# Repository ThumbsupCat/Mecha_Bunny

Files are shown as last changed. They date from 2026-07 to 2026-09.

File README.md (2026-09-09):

# Mecha-Iepurele (Mechanized Bunny)

**Author:** Alice Dobre
**Date:** 2026-07-20  

> Documentation draft generated from Agent 0 and Agent 1 outputs.  
> AI assists. Humans decide.

## 1. Introduction

Mecha-Iepurele (Mechanized Bunny) is an interactive, moving robotic companion designed for indoor flat surfaces (classroom, table, or smooth floor). The robot engages in natural conversations with humans via a cloud-based Conversational AI API and physically tracks and follows the user. High-level network operations (Wi-Fi connectivity, HTTPS API transactions, JSON payload parsing, and direct Text-to-Speech audio rendering via an I2S DAC) are offloaded to an ESP32 coprocessor suite (ESP32-S3 Nano), while low-level motor control loops, servo ear, active steering, battery monitoring, and sensor processing are managed by the main microcontroller board.

The purpose of this project is to create an engaging physical robotic companion that bridges low-level embedded hardware (sensors, motor drivers, PWM actuators, power management) with cloud-based artificial intelligence. The project originated from a concept for a mechanized bunny that talks to users, mimics emotional expressions based on conversation mood, and follows the user.

This project is especially valuable for third-year Computer Science students participating in the Embedded Engineering and Gen AI Summer School, as it teaches core embedded concepts (UART communication, PWM signal generation, I2C/I2S interfacing, control loops, power isolation, and software debouncing) as well as networking, API parsing, privacy protection, and system integration.

The **NXP FRDM-MCXA153 board featuring the NXP MCXA153 MCU** is selected as the mandatory target controller for all summer school projects. It provides Arm Cortex-M33 real-time processing, low-power timer peripherals, LPUART interfaces, and ADC channels required for local actuator control and sensor processing.

> This documentation is a draft and must be validated by students and instructors before implementation.

---

## 2. General Description

### 2.1 Project Summary

- **Project Name:** Mecha-Iepurele (Mechanized Bunny)
- **Author / Student Team:** TODO: Add Student Author(s) Name(s) and Student ID(s)
- **Short Summary:** An interactive, moving mechanized bunny robot that communicates with a human via an AI API (over ESP32 Wi-Fi) and mimics emotional expressions using physical movement (ear sweeps states).
- **Main Objective:** Build a robotic companion that uses a FRDM-MCXA153 board for local sensor-motor control and expressions, and an ESP32-S3 Nano for Wi-Fi connection to a cloud conversational AI API that provides responses and mood data.
- **Intended Users:** Third-year university Computer Science students and summer school reviewers/instructors.
- **Operating Environment:** Indoor flat surfaces (classroom, laboratory table, or smooth floor) with active Wi-Fi connectivity.
- **Selected Scope:** Recommended Summer School Version featuring mobile hopping locomotion via a single central DC motor driving a double-crank axle, active steering via a rear tail-skid servo, ear expression servos, ultrasonic user tracking, direct I2S TTS voice output on the ESP32, and onboard USB-C 2S LiPo balance charging.
- **Main Behavior:** Upon boot, the bunny initializes peripherals and connects to Wi-Fi. When user conversation is triggered, the ESP32 queries the cloud AI API, receives text response and mood data, and streams TTS voice output through an I2S DAC/speaker. The ESP32 sends servo targets to the MCXA153 via UART (with ACK confirmation). The MCXA153 updates ear servos (drooping for sad, perking for happy) state. Concurrently, a 50 ms motor control loop reads an ultrasonic sensor to track user distance (maintaining 30–50 cm) and drives the central hopping DC motor and steering tail-skid servo to follow the user smoothly.
- **Inputs:**
  - Ultrasonic distance sensor (RCWL-1601 / HC-SR04P, 3.3V compatible) measuring user distance.
  - Tactile physical buttons (setup / Wi-Fi provisioning / emergency stop).
  - Wi-Fi connection to Cloud LLM/NLP API (via ESP32-S3 Nano coprocessor).
  - Battery voltage diagnostic signal via resistor divider to ADC.
- **Outputs:**
  - 1x Central high-torque DC TT gear motor (via TB6612FNG H-bridge driver) for 90-degree kick hopping locomotion.
  - 4x SG90 Micro Servos (2x ears, 1x rear steering tail-skid).
  - MAX98357A I2S Audio DAC + 8 Ohm 2W speaker (driven directly by ESP32-S3 Nano).
- **Out-of-Scope Items:**
  - On-board execution of heavy Large Language Models (LLMs) or local Speech-to-Text on the MCXA153.
  - High-speed navigation on rough terrain or stairs.
  - Complex multi-obstacle collision avoidance beyond tracking the primary user.
  - Custom cloud backend hosting (standard pre-existing HTTP REST AI endpoints are assumed).
  - Status LEDs (all status feedback is expressed organically through physical ear movements).
  - OLED screen displays and local web input pages (in the speech TTS direct-drive edition).

### 2.2 Feature Tiers

| Tier | Description | Main Features | Extra Components | Main Risks | Suitability |
|---|---|---|---|---|---|
| **Core** | Static Ear desktop prototype in shell | ESP32-S3 Nano Wi-Fi handshake, queries mock/REST API, direct TTS audio via I2S MAX98357A DAC, MCXA153 drives 2x ear servos, NVS data wiping, UART ACK comms | ESP32-S3 Nano, MAX98357A DAC + Speaker, 2x Ear Servos, 3D Printed Shell & Brackets | UART framing errors, Wi-Fi handshake timeout, API parsing failure | **High suitability:** Focuses on serial comms, basic GPIO, and PWM servo control. Realistic for early development. |
| **Recommended** | Mobile Speech Companion (Selected Target Scope) | All Core features plus differential hopping leg linkage (1x central DC TT motor + H-bridge) executing gentle 90-degree kicks, active steering rear tail-skid, ultrasonic distance tracking (30–50 cm window), 50 ms motor loop, battery ADC monitoring (<6.4V sleep), 2S LiPo balance charging via USB-C port, magnetic quick-release ventilated shell | 1x DC TT Motor, TB6612FNG Driver, 3.3V Ultrasonic Sensor, 2S LiPo Battery & BMS, 2S USB-C Balance Charger Module, 4x Servos (Ears, Steering), USB-C Panel Cable, MR85ZZ Bearings, PETG/TPU Filaments | Mechanical binding, leg joint wear, high component density heat, ground impact shock, battery over-discharge | **Good with guidance:** Combines PWM, control loops, mechanical kinematics, power isolation, and safety. Excellent depth. |
| **Advanced** | Voice-Input Speech Companion | All Recommended features plus local I2S MEMS microphone (INMP441) on ESP32-S3 Nano for voice command streaming, wake-word detection / TinyML keyword spotting, local fuel gauge | INMP441 I2S MEMS Mic, LiPo Fuel Gauge IC, Camera module (ESP32-CAM / HuskyLens) | Acoustic feedback loops, double-buffered I2S timing, high power draw, memory limits | **Low (Optional extension):** Suitable only as a capstone extension for advanced teams due to time limits. |

### 2.3 Scenarios

| ID | Scenario | Description |
|---|---|---|
| `SC-001` | Startup / Setup | Device powers on. MCXA153 initializes GPIOs, LPUART, ADC, and PWM timers. ESP32-S3 Nano reads Wi-Fi credentials from NVS and connects to Wi-Fi. Upon successful connection, ESP32 sends "Online" byte over UART. MCXA153 sweeps ears to neutral to confirm awake state. |
| `SC-002` | Dynamic Wi-Fi Provisioning | If Wi-Fi fails within 15 seconds or setup button is held for 5 seconds at boot, ESP32 launches an Access Point setup portal. Ears move slowly to indicate search state. User connects via smartphone, submits credentials, and ESP32 connects and the ears showing attention state. |
| `SC-003` | Multi-User Device Wiping | Tester A finishes testing. Tester A holds setup button for 10 seconds. ESP32 erases all stored Wi-Fi credentials, tokens, and caches from NVS, reboots, sweeps ears to neutral to sleep. |
| `SC-004` | Onboard Battery Charging | When battery drops below 6.4V, MCXA153 halts motors. User plugs standard 5V USB-C cable into shell port. Integrated 2S balance charger charges cells to 8.4V. |
| `SC-005` | Normal Operation & Speech Playback | Conversation is triggered. ESP32 queries Cloud AI REST API, receives JSON (response text, mood tag, servo angles), extracts servo targets, and requests TTS audio stream. ESP32 renders audio via I2S to MAX98357A DAC. |
| `SC-006` | Active Privacy Cleansing | Speech playback completes. ESP32 immediately fills audio buffers and text RAM strings with zeros (`0x00`). Subsequent API calls use a newly generated, isolated session UUID to prevent user profiling. |
| `SC-007` | Actuator Expression Control | ESP32 sends parsed servo angles and mood data over LPUART to MCXA153. MCXA153 updates FTM/TPM PWM registers, driving ear servos to sweep to target angles (drooping for sad, perking for happy). |
| `SC-008` | Distance Sensor Processing | MCXA153 runs a periodic 50 ms motor loop. It triggers the ultrasonic sensor with a 10 us pulse, measures Echo pin return duration, and calculates distance in centimeters. |
| `SC-009` | Proximity Hopping & Steering | User is detected at 80 cm, offset right. MCXA153 drives central DC motor via PWM. Shared double-crank axle sweeps leg linkages past 90 degrees vertical, executing a gentle downward shove that hops chassis forward. Simultaneously, steering servo pivots rear tail-skid right for a smooth turn, slowing down as distance reaches 30–50 cm window. |
| `SC-010` | Safety & Reliability (Sleep Halt) | Emergency stop button is pressed, sensor Echo hangs >250 ms, or battery falls <6.4V. MCXA153 forces motor PWM to 0%, pulls motor driver STBY low, centers steering servo, droops ears to asleep state. |

### 2.4 User Stories

| ID | User Story |
|---|---|
| `US-001` | As a student developer, I need to use the NXP FRDM-MCXA153 board, so that the project complies with the course's mandatory hardware platform. |
| `US-002` | As a user, I need the bunny to dynamically connect to different Wi-Fi networks using a setup mode, so that I can easily bring the companion to new environments. |
| `US-003` | As a tester, I need to easily wipe my Wi-Fi credentials and conversation logs from the device, so that my personal network keys and private voice contents are not exposed to subsequent testers. |
| `US-004` | As a tester, I need the communication to be encrypted and my conversation session ID to be isolated, so that my conversations cannot be intercepted on local Wi-Fi or linked to other testers' profiles. |
| `US-005` | As a user, I need the bunny to convey its state of sleep and activity through physical movements of the ears, so that it looks like an organic creature without unnatural flashing LEDs. |
| `US-006` | As a developer, I need to power the motors and microcontrollers from a single large LiPo battery with separate regulators, so that logic circuitry is fully isolated from motor transients. |
| `US-007` | As a user, I want the bunny to move by hopping like a real rabbit, utilizing a robust leg linkage system that avoids binding, joint wear, and synchronization failures. |
| `US-008` | As a builder, I need structural mounts and leg linkages printed with PETG filament and low-friction bearings, so that the hopping mechanism has high toughness and structural durability. |
| `US-009` | As a builder, I need a spacious ventilated body shell with magnetic latches, an onboard USB-C 2S balance charger, and a 2S BMS protection board, so that components fit safely and battery charging is convenient and safe. |
| `US-010` | As a student builder with a 7-week project timeline, I need pre-designed mechanical model templates (STL/STEP) to build from, or I must strictly limit custom Blender CAD learning and design to a maximum of 1 week. |
| `US-011` | As a user, I need the bunny to be able to take motion turns when necessary, so that it can steer around obstacles or track my position as I turn corners. |
| `US-013` | As a builder, I want a non-piston leg linkage that hops the whole body by rotating the leg to 90 degrees relative to the body, executing a gentle low-amplitude hop to keep the movement stable and protect components. |

### 2.5 Use Case Diagram

```mermaid
flowchart LR
    Student[Student Developer]
    User[User / Tester]
    Instructor[Instructor / Reviewer]

    UC1((Initialize System & Hardware))
    UC2((Provision Wi-Fi Credentials))
    UC3((Trigger Conversation Session))
    UC4((Query Cloud AI & Stream TTS))
    UC5((Animate Ear Expressions))
    UC6((Track User & Proportional Hop))
    UC7((Pivot Rear Steering Tail-Skid))
    UC8((Trigger Organic Sleep / Halt))
    UC9((Wipe Credentials & Clean RAM))
    UC10((Charge 2S LiPo via USB-C))
    UC11((Review Test Evidence & Code))

    Student --> UC1
    User --> UC2
    User --> UC3
    UC3 --> UC4
    UC4 --> UC5
    UC3 --> UC6
    UC6 --> UC7
    User --> UC8
    User --> UC9
    User --> UC10
    Instructor --> UC11
```

### 2.6 Hardware and Software Block Diagram

```mermaid
flowchart TD
    subgraph PowerSystem["Power Subsystem"]
        BAT["2S LiPo Battery (7.4V - 8.4V)"]
        BMS["2S BMS Protection Board (6.0V Cutoff)"]
        CHG["2S Balance Charger Module (IP2326/TP5100)"]
        USBC["Panel USB-C Port"]
        REG_LOGIC["3.3V / 5.0V Logic Regulator"]
        REG_MOTOR["5.0V / 6.0V Motor & Servo Regulator"]
        BATT_DIV["Resistor Voltage Divider (10k / 4.7k)"]

        USBC --> CHG
        CHG --> BMS
        BAT <--> BMS
        BMS --> REG_LOGIC
        BMS --> REG_MOTOR
        BMS --> BATT_DIV
    end

    subgraph ESP32Core["ESP32-S3 Nano Coprocessor"]
        WIFI["Wi-Fi 2.4GHz Engine"]
        REST["HTTPS Client & JSON Parser"]
        I2S_OUT["I2S Digital Audio Output"]
        NVS["NVS Storage (Credentials & Keys)"]
    end

    subgraph MCUCore["NXP FRDM-MCXA153 Main Controller"]
        LPUART["LPUART Interface (115200 8-N-1)"]
        PWM_TIMERS["FTM / TPM Timer PWM Generators"]
        GPIO_CTRL["GPIO Controllers"]
        ADC_CTRL["12-bit ADC Input"]
        SUPERLOOP["Superloop & State Machine Task"]
    end

    subgraph AudioOutput["Audio Output Subsystem"]
        DAC["MAX98357A I2S DAC Amplifier"]
        SPK["8 Ohm 2W Speaker"]
        DAC --> SPK
    end

    subgraph ActuatorsSensors["Sensors & Actuators"]
        US_SENS["Ultrasonic Distance Sensor (RCWL-1601)"]
        EAR_L["Left Ear Servo (SG90)"]
        EAR_R["Right Ear Servo (SG90)"]
        STEER["Rear Steering Servo (SG90)"]
        TB6612["TB6612FNG H-Bridge Motor Driver"]
        DCMOTOR["Central DC TT Gear Motor"]
        ESTOP["Emergency Stop / Setup Button"]
        LINKAGE["Double-Crank Hopping Leg Linkage (PETG)"]

        TB6612 --> DCMOTOR
        DCMOTOR --> LINKAGE
    end

    %% Power distribution flow
    REG_LOGIC -.->|3.3V Power| ESP32Core
    REG_LOGIC -.->|3.3V Power| MCUCore
    REG_LOGIC -.->|3.3V Power| US_SENS
    REG_MOTOR -.->|5V/6V Power| DAC
    REG_MOTOR -.->|5V/6V Power| EAR_L
    REG_MOTOR -.->|5V/6V Power| EAR_R
    REG_MOTOR -.->|5V/6V Power| STEER
    REG_MOTOR -.->|5V/6V Power| TB6612

    %% Inter-processor data flow
    ESP32Core <== LPUART ACK Protocol ==> MCUCore
    I2S_OUT ==> DAC

    %% MCU Control connections
    BATT_DIV --> ADC_CTRL
    US_SENS <== GPIO / Capture ==> MCUCore
    ESTOP --> GPIO_CTRL
    PWM_TIMERS --> EAR_L
    PWM_TIMERS --> EAR_R
    PWM_TIMERS --> STEER
    PWM_TIMERS --> TB6612
    GPIO_CTRL --> TB6612
```

**System Architecture Explanations:**

- **Power Flow:** Power originates from a 2S LiPo battery pack (7.4V nominal, 8.4V max) connected through a 2S BMS protection board (6.0V cutoff). Power is split into two independent buck/LDO regulators: a digital logic regulator supplying 3.3V to the MCXA153, ESP32-S3 Nano, and ultrasonic sensor; and a motor/actuator regulator supplying 5.0V/6.0V to the TB6612FNG driver, MAX98357A DAC, and 4x SG90 servos. An onboard 2S USB-C balance charger (IP2326 or TP5100) charges the pack via a shell-mounted USB-C port.
- **Data & Control Flow:** The ESP32-S3 Nano executes Wi-Fi handshakes and cloud HTTPS transactions. Audio data streams directly over I2S to the MAX98357A DAC and speaker. Parsed servo targets, mood data, and system commands are sent to the MCXA153 over LPUART at 115200 baud. The MCXA153 validates checksums, returns software ACK bytes, updates servo PWM registers, and executes the 50 ms ultrasonic distance tracking loop to modulate the central DC motor and steering servo.
- **Compatibility Concerns:** MCXA153 GPIO pins operate strictly at 3.3V (max 4 mA per pin). Motor and servo power rails must never connect to MCU logic pins. A 3.3V-compatible ultrasonic sensor (RCWL-1601) is used, or a 10k/4.7k resistor divider is inserted on the Echo pin if using 5V HC-SR04 models. Battery voltage (up to 8.4V) is scaled down via a 10k/4.7k divider so the ADC receives <= 2.68V.
- **Protection & Decoupling:** Decoupling capacitors (100 uF electrolytic + 0.1 uF ceramic) are placed across power rails near the motor driver and servos to suppress inductive current spikes and prevent MCU brownouts. A freewheeling diode protection network is integrated inside the TB6612FNG driver.
- **Datasheet Checks Required:**
  - NXP MCXA153 reference manual: verify LPUART0 pin muxing, FTM/TPM timer channel assignments, and 12-bit ADC input channels.
  - TB6612FNG datasheet: check VM logic input ranges, logic VCC (3.3V), and STBY pin pull-down behavior.
  - MAX98357A datasheet: verify bit clock (BCLK), word select (LRCK), and serial data (SDIN) timing parameters for ESP32 I2S.
  - 2S BMS & Charger datasheets: confirm overcharge threshold (4.25V) and over-discharge threshold (3.0V per cell).

---

## 3. Hardware Design

### 3.1 Bill of Materials

| # | Component | Qty | Tier | Purpose | Likely Interface | Voltage / Power Notes | Risks / Checks |
|---|---:|---:|---|---|---|---|---|
| 1 | NXP FRDM-MCXA153 | 1 | Core | Central low-level MCU board for motor loop, PWM servos, ADC, and distance timing | LPUART, PWM, GPIO, ADC | 3.3 V Logic; Powered via USB-C or regulated 3.3V pin | Mandatory board. Verify pinout and 3.3V logic boundaries. |
| 2 | ESP32-S3 Nano | 1 | Core | Wi-Fi coprocessor, HTTPS API client, JSON parser, I2S audio renderer, NVS storage | LPUART, I2S, Wi-Fi | 3.3 V Logic; Powered via regulated 3.3V rail | Confirm NVS data wiping and 115200 baud UART link. |
| 3 | MAX98357A I2S DAC | 1 | Core | Direct digital audio decoding and amplification for voice TTS output | I2S (BCLK, LRCK, DIN) | Powered via 5V rail; 3.3V I2S logic from ESP32 | Audio noise from power ripples; route I2S away from UART. |
| 4 | Dynamic Speaker (8 Ohm, 2W) | 1 | Core | Voice TTS output speaker | Direct wire to DAC | Driven by MAX98357A DAC output | Ensure secure mounting inside head/body shell. |
| 5 | SG90 Micro Servos | 4 | Core / Rec | Physical actuators: 2x Ears, 1x Rear Steering Tail-skid | FTM/TPM PWM (50 Hz) | 5V Power rail; 3.3V PWM control logic | Current spikes during stall can reset MCU; use dedicated 5V regulator. |
| 6 | High-Torque DC TT Gear Motor | 1 | Recommended | Drives shared double-crank axle for 90-degree kick hopping locomotion | PWM + 2x GPIO (TB6612) | Powered via 5V-6V motor regulator rail | Inductive noise spikes; require freewheeling diodes & decoupling. |
| 7 | TB6612FNG H-Bridge Motor Driver | 1 | Recommended | Controls speed and direction of central DC gear motor | PWM, 2x GPIO, STBY pin | VM 5V-6V, VCC 3.3V logic | Verify STBY pin default low for safe shutdown. |
| 8 | Ultrasonic Distance Sensor (RCWL-1601) | 1 | Recommended | Measures distance to user (30-50 cm window) for proportional following | GPIO Trigger / Echo Capture | 3.3V Power & Logic | Sensor timeout hang; software 250ms watchdog required. |
| 9 | 2S LiPo Battery Pack (7.4V, 1500+ mAh) | 1 | Recommended | Main power source for mobile robot | 2S JST-XH balance + XT30/T-plug | 7.4V nominal (8.4V max, 6.0V cutoff) | Fire / thermal hazard; requires BMS board & balance charger. |
| 10 | Dual Buck / LDO Regulators | 2 | Recommended | Independent voltage regulation: 1x 3.3V logic, 1x 5V/6V motor & servos | Power rails | Input 7.4V; Output 3.3V and 5.0V | Heat dissipation; check continuous current ratings (>= 2A for motor rail). |
| 11 | 2S USB-C Balance Charger Module (IP2326/TP5100) | 1 | Recommended | Onboard USB-C balance charging for 2S battery pack | USB-C input, 2S balance output | Input 5V USB-C; Output 8.4V balance charge | Verify auto cut-off at 8.4V. |
| 12 | 2S LiPo BMS Protection Board | 1 | Recommended | Battery safety cutoff (overcharge, over-discharge, overcurrent) | Series battery connection | Cutoff at 6.0V overall pack voltage | Verify overcurrent protection >= 4A. |
| 13 | USB-C Panel Mount Extension Cable | 1 | Recommended | Exposes charging port to outer body shell | USB-C | 5V 2A pass-through | Ensure solid mounting on shell exterior. |
| 14 | MR85ZZ Ball Bearings | 8-12 | Recommended | Low-friction pivot bearings for double-crank leg linkages | Mechanical press-fit | N/A | Prevents mechanical binding and motor stalls. |
| 15 | Neodymium Magnets (4x2 mm) | 8-12 | Recommended | Toolless quick-release magnetic latches for outer body shell | Mechanical recess | N/A | Allows instant access to debugger and internal electronics. |
| 16 | M3 Socket Fastener Kit | 1 pack | Core / Rec | Structural assembly screws, nylon locknuts, and washers | Mechanical | N/A | Ensure nylon locknuts prevent loosening during hopping. |
| 17 | Tactile Push Buttons | 2 | Core / Rec | Setup / Wi-Fi provisioning button & Emergency Stop button | GPIO with internal pull-up | 3.3V Logic | Software debouncing required (20 ms window). |
| 18 | PETG 3D Filament | ~300g | Recommended | Structural mounts, crank arms, steering brackets, leg links | 3D Printed | N/A | High impact toughness required for hopping landing stress. |
| 19 | TPU 3D Filament | ~100g | Recommended | Flexible feet landing pads and shock absorbers | 3D Printed | N/A | Shore hardness ~95A for ground traction and shock damping. |
| 20 | PLA 3D Filament | ~300g | Recommended | Spacious outer body shell (~180x120x120 mm) with ventilation grilles | 3D Printed | N/A | Non-stress enclosure. Sourced STL files recommended. |

### 3.2 Hardware Block Diagram Description

The Mecha-Iepurele hardware architecture is organized around a dual-processor design to isolate real-time motor and sensor control from network latency:

- **Main Controller (NXP FRDM-MCXA153):** Serves as the central low-level executive. It runs a deterministic 50 ms superloop that handles PWM generation for 4x SG90 servos (left ear, right ear, , rear steering tail-skid), PWM speed and direction control for the central DC motor via the TB6612FNG H-bridge, GPIO pulse timing for the ultrasonic distance sensor, ADC voltage sampling for battery diagnostic monitoring, and UART packet parsing with ACK generation.
- **Coprocessor (ESP32-S3 Nano):** Manages all high-level Wi-Fi communications, TLS encryption, REST API transactions with the cloud AI endpoint, JSON response extraction, NVS credential storage/wiping, and direct I2S digital audio decoding to the MAX98357A DAC.
- **Power Architecture:** Powered by a single 2S LiPo battery pack (7.4V nominal, 8.4V max). Safety boundaries are enforced by a 2S BMS protection board that disconnects power if overall pack voltage drops to 6.0V (3.0V per cell) or current exceeds 4A. Two independent voltage regulators are fed from the BMS output: a 3.3V logic regulator powers the MCXA153, ESP32-S3 Nano, and ultrasonic sensor; a separate 5.0V/6.0V high-current regulator powers the TB6612FNG motor driver, 4x SG90 servos, and MAX98357A audio DAC. Battery voltage is monitored via a 10k / 4.7k resistor voltage divider connected to an ADC pin on the MCXA153 (delivering <= 2.68V at fully charged 8.4V). Onboard balance charging is achieved via an IP2326 or TP5100 2S balance charger module connected to a panel-mounted USB-C port on the outer shell.
- **Sensors & Actuators:**
  - *Ultrasonic Distance Sensor:* RCWL-1601 (3.3V native) mounted on the front chest/head to measure user distance.
  - *Hopping Locomotion:* 1x central DC TT gear motor drives a shared double-crank axle. Left and right leg linkages are physically locked in phase to the axle, preventing tipping. The leg linkages act as rotary levers; when sweeping through the 90-degree vertical angle relative to the chassis, they execute a gentle downward shove against the ground, lifting the body 5–15 mm into a forward hop/scoot. MR85ZZ ball bearings at all pivot joints minimize friction, while TPU pads on the feet absorb landing shock.
  - *Active Steering:* An SG90 micro servo pivots a rear tail-skid or caster assembly left/right by +/-30 degrees to steer the robot dynamically during hopping.
  - *Organic Expression Actuators:* 2x SG90 servos sweep the ears (drooped = sad, perked = happy/listening, neutral = idle);
- **Protection & Compatibility:** Logic connections between 3.3V MCU pins and 5V components use resistor dividers or 3.3V native modules. Decoupling capacitors (100 uF electrolytic + 0.1 uF ceramic) buffer voltage dips near the motor driver and servos. Datasheet reviews must verify pin mux assignments in MCUXpresso Config Tool, LPUART baud rate clocks, and ADC reference voltage calibration.

### 3.3 Pin Allocation Draft

Generic FRDM-MCXA153 capability only - exact pin requires board pinout and datasheet verification.

| Component | Tier | Signal | Required MCU Capability | Suggested Pin / Capability | Voltage Level | Direction | Interface | Verification Needed |
|---|---|---|---|---|---|---|---|---|
| ESP32-S3 Nano | Core | UART_TX | LPUART RX input | Generic LPUART0_RX | 3.3 V | Input | UART (115200) | Confirm configuration matches LPUART peripheral routing in MCUXpresso Pin Mux tool. |
| ESP32-S3 Nano | Core | UART_RX | LPUART TX output | Generic LPUART0_TX | 3.3 V | Output | UART (115200) | Verify TX buffer is set to push-pull drive and baud rate clock is accurate. |
| Battery Sense | Rec | BATT_VSENSE | ADC Analog Input | Generic ADC Channel | <= 2.68 V | Input | Analog ADC | Verify 10k/4.7k resistor divider output does not exceed 3.3V at 8.4V max battery charge. |
| Left Ear Servo | Core | SERVO_PWM_L | Timer PWM output (FTM/TPM) | Generic PWM Channel 0 | 3.3V Logic / 5V Power | Output | PWM (50 Hz) | Scope PWM pulse widths (1.0 - 2.0 ms) under load; confirm 20 ms period. |
| Right Ear Servo | Core | SERVO_PWM_R | Timer PWM output (FTM/TPM) | Generic PWM Channel 1 | 3.3V Logic / 5V Power | Output | PWM (50 Hz) | Verify servo operates smoothly without causing MCU brownouts. |
| Steering Servo | Rec | SERVO_PWM_STEER | Timer PWM output (FTM/TPM) | Generic PWM Channel 5 | 3.3V Logic / 5V Power | Output | PWM (50 Hz) | Verify PWM controls rear tail-skid steering angle (+/-30 degrees) without binding. |
| Motor Driver (TB6612) | Rec | MOTOR_PWM | Timer PWM output (FTM/TPM) | Generic PWM Channel 2 | 3.3 V | Output | PWM (10 kHz) | Verify speed modulation carrier frequency of central DC TT motor. |
| Motor Driver (TB6612) | Rec | MOTOR_DIR1 | GPIO Output | Generic GPIO pin | 3.3 V | Output | GPIO | Check forward/reverse direction transitions. |
| Motor Driver (TB6612) | Rec | MOTOR_DIR2 | GPIO Output | Generic GPIO pin | 3.3 V | Output | GPIO | Verify complementary logic state to DIR1. |
| Motor Driver (TB6612) | Rec | STBY | GPIO Output | Generic GPIO pin | 3.3 V | Output | GPIO | Verify internal/external pull-down puts motor driver in standby on reset/fault. |
| Ultrasonic Sensor | Rec | TRIG | GPIO Output | Generic GPIO pin | 3.3 V | Output | GPIO Pulse | Confirm 10 us trigger pulse duration accuracy via SysTick/timer. |
| Ultrasonic Sensor | Rec | ECHO | GPIO Input Capture / Interrupt | Generic Input Capture pin | 3.3 V (level-shifted) | Input | Pulse Width | Verify level shifting / 3.3V sensor compatibility on Echo pulse return line. |
| Emergency Stop | Rec | STOP_BTN | GPIO Input with Pull-up | Generic Interrupt GPIO | 3.3 V | Input | GPIO (Interrupt) | Verify internal pull-up resistor and software debouncing (20 ms window). |
| Setup / Provisioning | Core | SETUP_BTN | GPIO Input with Pull-up | Generic Interrupt GPIO | 3.3 V | Input | GPIO (Interrupt) | Verify 5s hold launches AP mode and 10s hold formats NVS storage. |

*Note: All I2S connections (BCLK, LRCK, DIN) to the MAX98357A DAC are routed directly from the ESP32-S3 Nano GPIO pins and are not connected to the MCXA153.*

### 3.4 Electrical Schematics

- `TODO: Add final schematic image or link.`
- `TODO: Add motor driver wiring diagram.`
- `TODO: Add sensor connection diagram.`
- `TODO: Add power distribution diagram.`

### 3.5 Signal Diagrams and Measurements

- `TODO: Add ultrasonic sensor Trigger and Echo signal capture.`
- `TODO: Add LPUART serial debug capture showing ACK packet transmission.`
- `TODO: Add power rail voltage measurement during motor startup and leg kick.`
- `TODO: Add total current measurement during hopping locomotion and speech output.`
- `TODO: Add timing analysis plot for the 50 ms motor loop and UART responsiveness.`

---

## 4. Software Design

### 4.1 Development Environment

- **Target Microcontroller:** NXP MCXA153 (Arm Cortex-M33) on FRDM-MCXA153 development board.
- **Coprocessor:** ESP32-S3 Nano (Dual-core Xtensa LX7).
- **IDE & Toolchain:** MCUXpresso VS Code Edition or MCUXpresso IDE.
- **SDK & Software Framework:** NXP MCUXpresso SDK for MCXA153 (`fsl_lpuart`, `fsl_gpio`, `fsl_tpm`/`fsl_ftm`, `fsl_adc16`, `fsl_clock`).
- **ESP32 Toolchain:** ESP-IDF or Arduino IDE with ESP32 board support package (handling Wi-Fi, mbedTLS, HTTP client, cJSON, and I2S driver).
- **Programming Language:** C (C99 standard).
- **Debugging Hardware:** On-board MCU-Link / SWD (Serial Wire Debug) debugger and USB-UART serial logging.

If development tools are unresolved, consult: `TODO: Confirm exact development environment, SDK version, build system, and flashing/debugging workflow.`

### 4.2 Firmware Architecture

- **Architecture Style:** Dual-processor asynchronous model. The MCXA153 executes a bare-metal superloop with periodic timer tasks, while the ESP32-S3 Nano handles event-driven networking and audio tasks.
- **Reason for Choice:** Separates real-time sensor processing and motor/servo timing on the MCXA153 from network latency, SSL handshakes, and audio buffering on the ESP32.
- **Main Firmware Modules (MCXA153):**
  - `main.c`: Superloop coordination, state machine management, and SysTick scheduler.
  - `uart_comm.c`: LPUART driver, RX frame buffer, CRC checksum validation, and ACK packet transmission.
  - `motor_driver.c`: TB6612FNG H-bridge direction and PWM speed control for central DC TT motor.
  - `servo_ears.c`: PWM angle generation (50 Hz) for left and right ear expression servos.
  - `steering_control.c`: PWM angle control (50 Hz) for rear tail-skid steering servo (+/-30 degrees).
  - `ultrasonic.c`: Trigger pulse generation and Echo input capture for distance measurement.
  - `battery_adc.c`: ADC 12-bit voltage sampling and under-voltage threshold check (<6.4V).
- **Startup Sequence:**
  1. Disable global interrupts.
  2. Configure system clocks to 48 MHz core frequency.
  3. Initialize GPIO ports, enabling internal pull-ups for buttons and default low states for motor driver STBY.
  4. Initialize LPUART0 peripheral (115200 baud, 8-N-1) and enable RX interrupts.
  5. Initialize FTM/TPM timers: TPM0 for motor PWM (10 kHz), TPM1 for ear, and steering servos (50 Hz).
  6. Initialize ADC peripheral (12-bit) and calibrate battery voltage channel.
  7. Configure SysTick timer for 1 ms tick interrupts.
  8. Enable global interrupts.
  9. Poll for ESP32 online handshake byte; upon receipt, sweep ears to neutral.
- **Main Loop / Task Flow (50 ms Loop):**
  - *Task 1 (LPUART Frame Check):* Parse incoming bytes from ESP32. If CRC is valid, send ACK byte (`0x06`) and update ear servo targets.
  - *Task 2 (Distance Tracking & Motor Control):* Trigger ultrasonic pulse, capture Echo width, and calculate distance. If Echo hangs >250 ms, enter safe shutdown. If distance is valid, compute error against 30–50 cm target window, adjust central DC motor PWM duty cycle and rear steering angle.
  - *Task 3 (Battery Check):* Sample battery ADC. If V < 6.4V, halt motor, droop ears, center steering to sleep.
  - *Task 4 (Watchdog Feed):* Refresh coprocessor watchdog timer.
- **Error Handling & Safe-State Strategy:**
  If UART communication drops for >3.0 s, battery voltage falls <6.4V, ultrasonic Echo hangs >250 ms, or emergency stop is pressed, the MCU immediately transitions to `SAFE_SHUTDOWN`. Central motor PWM is forced to 0%, motor driver STBY is pulled low, steering servo is centered, ears are drooped.
- **Configuration Constants:**
  - `BAUD_RATE`: 115200
  - `SERVO_PWM_FREQ_HZ`: 50
  - `MOTOR_PWM_FREQ_HZ`: 10000
  - `TARGET_DIST_MIN_CM`: 30 (AI Assumption)
  - `TARGET_DIST_MAX_CM`: 50 (AI Assumption)
  - `BATTERY_LOW_CUTOFF_V`: 6.4 (AI Assumption)
  - `UART_TIMEOUT_MS`: 3000 (AI Assumption)
  - `SENSOR_TIMEOUT_MS`: 250 (AI Assumption)

### 4.3 Main Algorithms and Data Structures

- **State Machine:** Enums defining system states: `STATE_INIT`, `STATE_WIFI_PROVISION`, `STATE_IDLE_AWAKE`, `STATE_CONVERSING`, `STATE_TRACKING_HOP`, `STATE_LOW_BATTERY`, `STATE_SAFE_SHUTDOWN`.
- **Proportional Distance Control Algorithm:**
  ```text
  distance = read_ultrasonic_cm()
  if (distance > TARGET_DIST_MAX_CM) {
      error = distance - TARGET_DIST_MAX_CM
      motor_speed = clamp(BASE_SPEED + Kp * error, MIN_SPEED, MAX_SPEED)
      set_motor_direction(FORWARD)
  } else if (distance < TARGET_DIST_MIN_CM) {
      error = TARGET_DIST_MIN_CM - distance
      motor_speed = clamp(BASE_SPEED + Kp * error, MIN_SPEED, MAX_SPEED)
      set_motor_direction(REVERSE)
  } else {
      motor_speed = 0
      set_motor_direction(STOP)
  }
  ```
- **Steering Control Algorithm:** Adjusts rear tail-skid servo angle based on relative obstacle position or steering command offset (+/-30 degrees relative to center).
- **UART Frame Data Structure:**
  ```c
  typedef struct {
      uint8_t header;       // 0xAA
      uint8_t cmd_type;     // 0x01 = Servo update, 0x02 = Mood, 0x03 = Status
      int8_t  ear_left_deg; // Angle 0 - 180
      int8_t  ear_right_deg;// Angle 0 - 180
      int8_t  steer_deg;    // Steering offset -30 to +30
      uint8_t crc8;         // Checksum
  } uart_payload_t;
  ```
- **Privacy Buffer Zero-Fill Routine:**
  Immediately after TTS playback completes on the ESP32, `memset(audio_buffer, 0, sizeof(audio_buffer))` and `memset(text_buffer, 0, sizeof(text_buffer))` are called to overwrite sensitive conversation contents in RAM.

### 4.4 Functional Requirements Summary

| ID | Tier | Requirement | Priority | Verification | Acceptance Criterion |
|---|---|---|---|---|---|
| `FR-001` | Core | The system shall use the NXP FRDM-MCXA153 board as the main controller for low-level sensor-motor control and real-time execution. | Must | Inspection | BOM confirms MCXA153 handles low-level actuator drive and real-time loop tasks. |
| `FR-002` | Core | The system shall use the ESP32-S3 Nano as the Wi-Fi, API, and audio parsing coprocessor. | Must | Inspection | Physical board layout includes the ESP32-S3 Nano connected to the MCXA153. |
| `FR-003` | Core | Upon power-on, MCXA153 shall initialize GPIOs, LPUART, ADC, and PWM timers, sweep ears to neutral, | Must | Test | Debug port outputs boot diagnostics; ears sweep to neutral. |
| `FR-004` | Core | The ESP32-S3 Nano shall perform a Wi-Fi handshake to connect to a local AP using credentials stored in NVS upon boot. | Must | Test | ESP32 logs show successful Wi-Fi connection using stored credentials. |
| `FR-005` | Core | ESP32-S3 Nano shall make HTTPS requests to the cloud AI API, parse JSON response, and extract servo angles and mood parameters. | Must | Test | JSON parser extracts data correctly from simulated API responses. |
| `FR-006` | Core | ESP32-S3 Nano shall directly parse and play back voice audio via I2S to MAX98357A DAC. No audio data shall be sent to MCXA153. | Must | Demo | Voice response is audible from speaker. Scope confirms no audio frames on UART link. |
| `FR-007` | Core | ESP32-S3 Nano shall transmit parsed servo and status parameters to MCXA153 over LPUART at 115200 baud, 8-N-1 formatting. | Must | Test | MCXA153 receives and parses UART commands containing correct angle targets. |
| `FR-008` | Core | MCXA153 shall actuate two SG90 ear servos using 50 Hz PWM signals to angles received from ESP32-S3 Nano. | Must | Demo | Ears move to commanded angles +/- 5 degrees. |
| `FR-009` | Rec | MCXA153 shall drive central DC TT motor via PWM (speed) and GPIO (direction) using TB6612FNG driver to actuate hopping double-crank axle. | Must | Test | PWM duty cycle and GPIO logic transition correctly matching motion commands. |
| `FR-010` | Rec | MCXA153 shall measure user distance in cm by triggering ultrasonic sensor and timing Echo pulse via GPIO capture. | Must | Test | Distance values resolve accurately within 2 cm to 150 cm window (+/- 2 cm tolerance). |
| `FR-011` | Rec | MCXA153 shall run a proportional control loop to drive central DC motor, keeping user within 30–50 cm window (AI Assumption). | Must | Demo | Robot hops forward when dist > 50cm, hops reverse when dist < 30cm, stops inside 30-50cm. |
| `FR-012` | Rec | MCXA153 shall monitor battery voltage via ADC divider. If V < 6.4V, disable motor, droop ears to sleep. | Must | Test | At V < 6.4V, motor stops, ears droop,|
| `FR-013` | Rec | Emergency stop button press shall force motor PWM to 0%, pull motor driver STBY low, center steering. | Must | Test | Button press halts legs within 50 ms, centers steering. |
| `FR-014` | Core | If UART comms with ESP32 drops > 3.0 s (AI Assumption), MCXA153 shall stop motor, center steering to sleep. | Must | Test | Disconnecting UART wire forces motor stop, steering centering. |
| `FR-015` | Rec | MCXA153 shall transmit a software ACK packet back to ESP32 upon successful receipt and CRC check of UART message. | Must | Test | ESP32 registers valid ACK byte within 100 ms of transmitting control frame. |
| `FR-016` | Rec | If ultrasonic Echo hangs > 250 ms (AI Assumption), MCXA153 shall stop motor, center steering, droop ears. | Must | Test | Disconnecting Echo pin triggers motor stop, steering center|
| `FR-017` | Rec | If ESP32 fails Wi-Fi within 15s or setup button held 5s, launch setup AP portal to save new Wi-Fi credentials to NVS. | Must | Test | Setup AP launches, accepts web credentials, and successfully saves them to NVS. |
| `FR-018` | Core | Holding setup button 10s at boot shall wipe all saved Wi-Fi credentials and tokens from NVS, and reboot. | Must | Test | Holding button 10s clears all stored credentials, verified by NVS check after reboot. |
| `FR-019` | Core | ESP32-S3 Nano shall generate a new random UUID session key upon boot/reset, preventing API conversation profile linking. | Must | Test | HTTP payloads show distinct, non-linked session UUIDs across boots and resets. |
| `FR-020` | Core | System shall overwrite all conversation text buffers and audio memory in RAM with zeros immediately after TTS speech completes. | Must | Test | Memory inspection confirms response text is overwritten in RAM immediately post-speech. |
| `FR-021` | Rec | Mechanical leg linkages shall be driven by 1x central DC TT motor rotating a shared double-crank axle to lock left/right leg phase. | Must | Inspection | Both leg drive cranks are physically pinned and locked in phase to the same motor axle. |
| `FR-022` | Rec | Power subsystem shall incorporate an onboard 2S balance charger connected to a USB-C shell port to charge battery without shell disassembly. | Must | Test | USB power delivery is negotiated; onboard charger balances and charges cells to 8.4V. |
| `FR-023` | Rec | Outer 3D printed shell shall have a spacious design (~180x120x120 mm) with airflow grilles and magnetic quick-release latches. | Must | Inspection | Shell houses all components without wire pinching, provides vents, and opens toollessly. |
| `FR-024` | Rec | MCXA153 shall actuate a steering micro servo (SG90) via 50 Hz PWM to pivot rear tail-skid +/-30 degrees for hopping turns. | Must | Test | Steering servo moves to target angles on command; tail-skid turns chassis dynamically. |
| `FR-025` | Rec | Leg linkages shall sweep through 90 degrees vertical, executing a gentle downward kick that lifts body 5-15 mm for a stable hop. | Must | Test | Continuous motor rotation sweeps legs past 90 degrees, lifting chassis off floor during kick. |

### 4.5 Non-Functional Requirements Summary

| ID | Tier | Category | Requirement | Metric / Threshold | Verification |
|---|---|---|---|---|---|
| `NFR-001` | Core | Safety / Electrical | All components connected to MCXA153 must be 3.3V logic compatible. Status feedback must not use LEDs. | GPIO V <= 3.3V; Current <= 4 mA/pin. Status conveyed via ear organically. Zero LEDs. | Inspection / Scope measurement |
| `NFR-002` | Core | Memory | Static RAM utilization of MCXA153 firmware must stay within MCU memory limits. | SRAM usage <= 28 KB (leaving 4 KB safety margin). (AI Assumption) | Compiler map file analysis (.map) |
| `NFR-003` | Rec | Power Isolation | Power MCU/ESP32 logic and motor via independent voltage regulators from shared 2S battery pack. | Regulated 3.3V logic, regulated 5V/6V motor; 10k/4.7k divider scales ADC <= 2.68V. | Inspection / Voltmeter measurement |
| `NFR-004` | Rec | Mechanical Filaments | Structural mounts and leg links printed strictly in PETG; joints use MR85ZZ bearings; feet use TPU. | Links: PETG; Feet: TPU; Shell: PLA; Bearings: MR85ZZ at all pivot pins. | Physical inspection / Filament spec audit |
| `NFR-005` | Rec | Timing | Motor control user-following loop must run at a deterministic periodic rate to prevent lag. | Control loop period 50 ms +/- 5 ms. (AI Assumption) | Test (GPIO toggle & logic analyzer trace) |
| `NFR-006` | Rec | Safety | If distance sensor readings hang or fail, system must immediately disable motor. | Stop motor  <= 100 ms of invalid sensor reading. (AI Assumption) | Test (pulling sensor pin / simulating fault) |
| `NFR-007` | Core | Wi-Fi Connection | ESP32 shall establish Wi-Fi link within a defined startup window before indicating search state. | Wi-Fi handshake timeout <= 15 seconds. (AI Assumption) | Test (forcing connection failures & timing) |
| `NFR-008` | Core | Privacy / Security | System shall encrypt all API network transactions to prevent conversation eavesdropping. | Enforce TLS 1.2 or higher for all HTTPS calls from ESP32. | Wireshark network packet sniffing |
| `NFR-009` | Advanced | Privacy / Security | Microphone must not record passively; active recording must require physical trigger button. | Recording starts only on button press. Active state shown via ear gesture (No LEDs). | Demonstration / Functional audit |
| `NFR-010` | Rec | Battery Safety | Battery power circuit must include an integrated 2S BMS board enforcing safety protection boundaries. | Cell overcharge 4.25V; over-discharge cutoff 3.0V (6.0V pack); overcurrent >= 4A. | Short-circuit & load test verification |
| `NFR-011` | Rec | CAD Sourcing & Timeline | Sourcing pre-designed STL/STEP models is highly recommended. Limit CAD design to max 1 week. | CAD learning & design phase <= 1 week of 7-week timeline. 100% files sourced/done. | Audit of file availability & project log |

### 4.6 Test Plan Summary

| Test ID | Requirement | Tier | Test Type | Expected Result | Evidence |
|---|---|---|---|---|---|
| `TC-001` | `FR-001` | Core | Inspection | Target controller is confirmed as NXP FRDM-MCXA153. Secondary coprocessors allowed. | Physical board photo & BOM inspection. |
| `TC-002` | `FR-003`, `FR-021` | Core | Test | Apply power; MCU boots, prints init log to serial console. | Diagnostic console log & video. |
| `TC-003` | `FR-007` | Core | Test | Connect ESP32 and MCXA153 UART lines; send test frames for 5 minutes. | Zero byte corruption / framing errors. Logic analyzer capture. |
| `TC-004` | `FR-005` | Core | Test | Send mock JSON payload to ESP32; monitor parser output. | JSON parser extracts servo angles and mood variables correctly. ESP32 serial logs. |
| `TC-005` | `FR-006` | Core | Test | Trigger audio playback on ESP32 connected to MAX98357A DAC. | DAC receives direct digital I2S frames and drives speaker smoothly. Audio waveform trace. |
| `TC-006` | `FR-006` | Core | Demo | Stream voice response to ESP32; measure audio loudness. | Voice response is clearly audible (sound level >= 70 dBA at 1 meter). Audio recording. |
| `TC-007` | `FR-014`, `FR-021` | Core | Test | Disconnect LPUART RX wire from MCXA153 during operation. | Motor stops, steering centers,. Timing capture log / video check. |
| `TC-008` | `FR-009` | Rec | Test | Suspend chassis; inject forward drive commands to central DC motor. | Motor spins; double-crank axle rotates smoothly without binding (current <= 300 mA). Current measurement log. |
| `TC-009` | `FR-010` | Rec | Test | Place obstacle at 50 cm distance from ultrasonic sensor. | Calculated distance displays as 50 cm +/- 2 cm. Tape measure vs debug log comparison. |
| `TC-010` | `FR-011`, `FR-022`, `FR-025` | Rec | Demo | Place robot on floor; move obstacle to 80cm then 20cm; send turn command. | Robot hops forward, steers tail-skid left/right, and maintains 30-50 cm window. Video of hopping turns. |
| `TC-011` | `FR-008` | Core | Demo | Send servo angle command for 45 degrees (drooped ears). | Ear servos sweep to 45 degrees; PWM pulse width measures 1.25 ms. Scope pulse width trace. |
| `TC-012` | `FR-012`, `FR-021` | Rec | Test | Drop battery source voltage below 6.4 V. | Motor disables immediately, ears droop, steering centers,. Multimeter check & video log. |
| `TC-013` | `FR-013`, `FR-021` | Rec | Test | Actuate motors at full speed; press Emergency Stop button. | DC motor PWM drops to 0%, steering centers <= 50 ms. Logic analyzer capture / video. |
| `TC-014` | `FR-015` | Rec | Test | Send UART packet from ESP32 to MCXA153; measure time to receive ACK. | MCXA153 returns ACK byte (`0x06`); ESP32 receives it in <= 100 ms. Logic analyzer trace. |
| `TC-015` | `FR-016`, `FR-021` | Rec | Test | Cut ultrasonic sensor Echo wire while robot is moving. | Safe shutdown task halts motor, centers steering. Debug log showing halt time. |
| `TC-016` | `FR-017`, `FR-021` | Rec | Test | Force Wi-Fi connection failure; submit credentials via setup AP portal. | setup portal saves keys to NVS; NVS dump & connection logs. |
| `TC-017` | `FR-018` | Core | Test | Hold setup button for 10 seconds at boot; inspect NVS memory. | Stored Wi-Fi keys and session caches are formatted/erased. NVS check post-reboot. |
| `TC-018` | `FR-020` | Core | Test | Complete TTS voice response; inspect ESP32 RAM buffers post-speech. | RAM memory addresses for text strings contain `0x00` zero-fill. Memory debugger dump. |
| `TC-019` | `FR-023` | Rec | Test | Connect 5V USB-C source to shell port with depleted battery (V < 7.0V). | Onboard balance charger negotiates power, balances cells, and stops at 8.4V +/- 0.05V. Charger status log / Voltmeter. |
| `TC-020` | `FR-025` | Rec | Test | Send steering angles (+30 deg, 0 deg, -30 deg) over UART. | Rear steering tail-skid rotates to target angle +/- 2 degrees without binding. Protractor measurement & video. |
| `TC-021` | `FR-026` | Rec | Test | Power central DC motor; capture leg linkage sweep in slow motion. | Legs sweep past 90 degrees vertical, delivering a downward push that lifts chassis 5-15 mm off floor. Slow-motion video review. |

### 4.7 Traceability Summary

| User Story | Requirement(s) | Test Case(s) | Evidence | Gap |
|---|---|---|---|---|
| `US-001` (Mandatory Board) | `FR-001` | `TC-001` | Physical board label photo & BOM inspection | None |
| `US-002` (Wi-Fi Portability) | `FR-002`, `FR-004`, `FR-017`, `NFR-007` | `TC-016` | AP setup portal screenshots & connection logs | None |
| `US-003` (Data Wiping & Privacy) | `FR-018`, `FR-020` | `TC-017`, `TC-018` | NVS post-wipe state check & RAM zero-fill debugger dump | None |
| `US-004` (Encrypted Comm) | `FR-019`, `NFR-008` | Network Sniffing Check | Wireshark TLS 1.2 validation & HTTP UUID capture | None |
| `US-005` (Power Isolation) | `FR-012`, `NFR-003` | `TC-012` | Schematic review, ADC calibration log, voltmeter check | None |
| `US-006` (Hopping Leg System) | `FR-009`, `FR-011`, `FR-022`, `NFR-004` | `TC-008`, `TC-010` | Video of forward/reverse hopping & double-crank drawing | None |
| `US-007` (Filaments & Bearings) | `NFR-004` | Inspection Check | Physical inspection of PETG/TPU prints & bearing assembly photo | None |
| `US-008` (Spacious Shell & Charger) | `FR-023`, `FR-024`, `NFR-010` | `TC-019`, Inspection | Charging current profile log, cell balance check, shell measurement | None |
| `US-009` (CAD Sourcing Time Limit) | `NFR-011` | Audit Check | Verify STL files exist & project log shows <= 1 week on CAD | None |
| `US-010` (Active Steering Turns) | `FR-025` | `TC-020` | Tail-skid linkage clearance check & video of motion turns | None |
| `US-011` (90-Degree Kick Locomotion) | `FR-026` | `TC-021` | Slow-motion video verifying 5-15 mm ground clearance lift | None |

---

## 5. Risk Matrix

| ID | Category | Tier Affected | Severity | Probability | Impact | Mitigation | Human Approval Required |
|---|---|---|---|---|---|---|---|
| `R-001` | Voltage / Power | Recommended | Low | Low | MCU brownout / reset when central DC motor starts | Separate independent regulators power MCU logic and motor path; decoupling capacitors placed near driver | No |
| `R-002` | Safety | Recommended | Medium | Low | Motor running indefinitely if ultrasonic sensor Echo hangs | Software 250 ms watchdog task (`FR-016`) halts motor, centers steering, droops ears | No |
| `R-003` | Mechanical Linkages | Recommended | High | Low | Brittle linkage joints fracturing under hopping ground impact | Leg linkages and structural mounts printed strictly in PETG (`NFR-004`); feet use TPU damping pads | No |
| `R-004` | Electrical | Recommended | Low | Medium | High motor current noise causing UART packet corruption | Implemented software ACK confirmation protocol (`FR-015`) to verify message delivery before next dispatch | No |
| `R-005` | Electrical | Core / Rec | High | Low | Connecting 5V sensor outputs directly to 3.3V MCU inputs damaging silicon | Native 3.3V modules used (RCWL-1601), or 10k/4.7k resistor voltage dividers inserted on feedback signals | No |
| `R-006` | Acoustic / EMI | Core | Low | Low | I2S audio signals creating crosstalk noise on LPUART lines | Physical trace separation: I2S and LPUART wiring routed in opposite directions using isolated copper wires | No |
| `R-007` | Privacy / Security | Core | High | Low | Stored Wi-Fi keys or conversation cache leaked between test users | 10-second button NVS wiping routine (`FR-018`), post-speech RAM zero-filling (`FR-020`), TLS encryption (`NFR-008`) | No |
| `R-008` | Mechanical Control | Recommended | Medium | Medium | Joint binding or phase drift between left and right legs causing tipping | Shared mechanical double-crank axle (`FR-022`) driven by 1x motor; MR85ZZ ball bearings at all pivot pins | No |
| `R-009` | Battery Safety | Recommended | High | Low | 2S LiPo battery overcharge, over-discharge, or thermal runaway | Integrated 2S balance charger (`FR-023`) and 2S BMS protection board (`NFR-010`) enforcing 6.0V cutoff | No |
| `R-010` | Thermal Heat | Recommended | Medium | Low | Component density inside closed shell causing thermal throttling | PLA outer body shell (`FR-024`) designed with multiple passive airflow ventilation grilles | No |
| `R-011` | Mechanical CAD Sourcing | Recommended | Medium | High | Learning CAD tools (e.g. Blender) consuming vital project time | Sourcing pre-designed STL/STEP templates is highly recommended; limit custom CAD design to max 1 week (`NFR-011`) | Yes |
| `R-012` | Steering Jamming | Recommended | Low | Low | Rear tail-skid steering linkage jamming against outer body shell | Linkage design enclosed within shell bounds with mechanical clearance >= 10 mm | No |
| `R-013` | Landing Impact Shock | Recommended | Medium | Low | Peak landing impact forces stripping TT gear motor teeth or cracking mounts | Jointed PETG legs with TPU landing pads absorb impact; 90-degree kick generates a gentle low-lift (5-15 mm) hop | No |

---

## 6. Assumptions and Open Questions

### 6.1 Confirmed Facts

- The project represents a Mechanized Bunny that has conversations with a human.
- The bunny physically follows the user using distance sensors.
- The bunny mimics emotional expressions based on conversation mood using physical ear sweeps.
- The bunny retrieves answers and mood data from a Cloud AI API endpoint.
- The target hardware suite is fixed: **NXP FRDM-MCXA153 board** as the main controller, and an **ESP32 coprocessor suite (ESP32-S3 Nano)** for Wi-Fi connectivity.
- Dual-processor architecture is permitted: MCXA153 manages low-level motor/servo timing and sensors; ESP32-S3 Nano manages Wi-Fi, HTTPS REST API, JSON parsing, and I2S audio rendering.
- Power is supplied by a single 2S LiPo battery pack with separate, independent regulators powering digital logic and motor paths.
- Structural mounts, crank arms, and leg linkages must be printed strictly in **PETG** filament; landing pads use **TPU**; body shell uses **PLA**.
- A software UART acknowledgment (ACK) protocol (`0x06`) is used to confirm command delivery.
- Logic interface matching uses resistor voltage dividers or native 3.3V modules.
- Status LEDs are completely excluded; state feedback (awake, searching, sleeping, low battery) is conveyed organically via physical ear sweeps.
- Locomotion is achieved by a hopping leg linkage driven by **1x central high-torque DC gear motor** rotating a shared double-crank axle to lock leg phase.
- Locomotion utilizes a 90-degree rotary leg kick generating a gentle, low-amplitude hop (5 to 15 mm lift).
- Active steering is achieved via an SG90 micro servo pivoting a rear tail-skid assembly (+/-30 degrees).
- Outer body shell is spacious (~180x120x120 mm) with airflow ventilation grilles and magnetic quick-release latches.
- Battery charging uses an onboard 2S USB-C balance charger module and 2S BMS protection board.
- The total project delivery duration for students is 7 weeks. Sourcing pre-designed 3D model files (STL/STEP) is highly recommended; custom CAD learning/design must be strictly capped at 1 week.

### 6.2 AI Assumptions

- `A-001` (Autonomous Network Flow): The bunny does not require a local smartphone app during normal operation; ESP32 connects directly to Wi-Fi upon boot using NVS keys.
- `A-002` (Cloud API Payload): Cloud API is an HTTP REST service returning a simple JSON object containing `reply` (string), `mood` (string), and `servo_angle` (integer).
- `A-003` (Coprocessor Division of Labor): ESP32-S3 Nano handles networking, SSL/TLS, API parsing, and direct I2S audio rendering; MCXA153 handles PWM motor/servos, ultrasonic timing, and battery ADC.
- `A1-001` (User Distance Thresholds): Target distance for user tracking is set to a 30–50 cm window.
- `A1-002` (Control Loop Period): The DC motor speed update control loop runs periodically every 50 ms.
- `A1-003` (Servo PWM Frequency): PWM control signals for ear and steering servos run at 50 Hz (20 ms period).
- `A1-004` (UART Configuration): LPUART link operates at 115200 baud, 8-N-1 formatting.
- `A1-005` (Battery ADC Scaling): 2S LiPo battery (8.4V max) is scaled down using a 10k / 4.7k resistor divider, delivering <= 2.68V to the ADC.
- `A1-006` (Spacious Shell Envelope): Outer shell dimensions are set to approximately 180 mm (L) x 120 mm (W) x 120 mm (H).
- `A1-007` (3D Asset Sourcing): 3D mechanical models and shell files are sourced from pre-existing course templates or open-source repositories.

### 6.3 Open Questions

| ID | Question | Why It Matters | Owner | Status |
|---|---|---|---|---|
| `Q-001` | What exact HTTP REST API endpoint and authentication header format will be used for the summer school Cloud AI service? | Determines JSON parsing key names and header buffer memory sizing on the ESP32-S3 Nano. | Instructor / Student | Open |
| `Q-002` | Are pre-designed 3D printable STL/STEP files for the double-crank leg linkage and spacious shell available in the course repository? | If templates are unavailable, student must immediately allocate 1 week of the 7-week timeline for custom Blender CAD design. | Instructor | Open |
| `Q-003` | What gear reduction ratio (1:120 vs 1:220) is preferred for the central DC TT gear motor? | Higher gear reduction (1:220) provides superior torque for lifting the chassis during the 90-degree kick phase but reduces hopping speed. | Student | Open |
| `Q-004` | What specific model of 2S USB-C balance charger module (IP2326 vs TP5100) will be supplied in the lab kit? | Affects PCB footprint mounting and USB-C panel wiring layout inside the shell. | Instructor / Student | Open |

---

## 7. Human Review Checklist

- [ x] Scope approved
- [ x] Selected feature tier approved (Recommended Summer School Version)
- [ x] FRDM-MCXA153 confirmed as mandatory target board for low-level control
- [ x] FRDM-MCXA153 pinout and LPUART / PWM peripheral assignments checked
- [ x] Voltage compatibility checked (3.3V logic boundaries enforced; zero 5V directly to MCU)
- [ x] Current limits checked (motor and servos powered from dedicated 5V/6V regulator rail)
- [ x] Power budget checked (2S LiPo battery, 2S BMS cutoff at 6.0V, 10k/4.7k ADC divider)
- [ x] External modules checked (RCWL-1601 ultrasonic, MAX98357A DAC, TB6612FNG driver)
- [ x] Advanced components approved or removed (Voice mic & camera reserved for Advanced tier)
- [ x] Sensor/actuator interfaces confirmed (Ultrasonic capture, 4x PWM servos, H-bridge DC motor)
- [ x] Firmware architecture approved (Dual-processor asynchronous superloop with UART ACK check)
- [ x] Timing and memory constraints reviewed (50 ms loop period, SRAM usage <= 28 KB)
- [ x] Test plan reviewed (TC-001 through TC-021 linked to Must requirements)
- [ x] Traceability reviewed (All user stories mapped to system requirements and test cases)
- [ x] Safety/privacy/security risks reviewed (TLS encryption, 10s button NVS wipe, RAM zero-fill)
- [ x] Implementation allowed to start

---

## 8. Obtained Results

```markdown
TODO: Complete after implementation.

Describe:
- what was implemented;
- what works;
- what does not work yet;
- measurements and test results;
- photos or screenshots;
- demo observations;
- limitations.
```

What was implemented:
  - MCXA153 motor test
  - ESP32-S3 Nano Microphone STT and outputing on Serial Monitor
  - UART communication between the MCXA153 and ESP32-S3 Nano by using a sample json

What works:
  - All the motors set on 35% duty cycle and being able to run over small carpets as well
  - Microphone recording clear voice samples
  - UART assures an acceptable speed for the type of data I want to communicate

What does not work yet:
  - The project requires merging all test suites
  - Servo motor data pins not set in stone
  - The ESP32 S3 needs to send the transcript to an LLM and receive the instructions for the MCXA and am answer to the user's phrase.
  - The MCXA needs to be able to translate the JSON data into actual movement.

Test Results:
  - SPIFFS not a dependable tool for this kind of task, decided to go for the PSRAM approach that is suitable for holding
audio samples or images without the need to write them on the disk
  - The motors are ready to be used with ease in the following translation
  - Microphone quality is perfect for this scope, by using the I2S_PHILIPS_SLOT_CONFIG

Limitations:
  - The bunny can't handle directly orders from the person if the sound comes from the front of it, only left and right. The front and back
can be handled by asking the user on which side the voice comes from.

---

## 9. Conclusions

```markdown
TODO: Complete at the end of the project.

Discuss:
- what was learned;
- what worked well;
- what was difficult;
- what would be improved in a future version;
- how Gen AI helped or failed to help.
```

What was learned:
  - Finding different approaches in transferring the data in an embedded environment with strict memory limitations
  - How to run different electronic components in a circuit.
  - How to correctly test every HW/SW integration by using a modular approach

What worked well:
  - Including all the features in different project workspaces to isolate SW bugs
  - The main functions that are being controlled by the microcontrollers worked flawlessly

What was difficult:
  - The microphone addition proved as a challenge due to my lack of knowledge in these modules,
it required me to also analyze the audio sample several times
  - The PWM section on MCUXpresso Config Tools is pretty hard to understand and I kept it in the source code
  - The API call for the OpenAI Whisper STT wasn't working initially to SSL handshake issues being extremely strict
on who accesses this API.

What would be improved in a future version:
  - I would like to include a more organic interaction by adding eyelids as a HW/SW feature.
  - Adding a model that can understand a person's mood by its voice (local)
  - Adding an easier battery charging by using a TP5100
  - I want to add 2 more microphones for distinguishing front and back

How Gen AI helped or failed to help:
  - Helped me with several initial configurations like I2S, and PWM. I had to edit them afterwards for fine tuning.
  - It failed in understanding the main issue regarding the audio samples recorded, being extremely loud and distorted
because it provided me with a configuration that didn't match. I analyzed the sound using external software like Audacity.
  - Initially, it couldn't provide me with a long-term setup for the audio sampling. SPIFFS proved to be having extreme
downsides regarding overheads (disk writting). Managed to replace with PSRAM, which is more suited for this scope.
  - It helped me building each test suite and worked on troubleshooting. I managed to provide data by troubleshooting the
physical side of the project by using a multimeter.
  - Helped me with double checking the respective wirings and schematic notations.
  - It failed to merge the components that have been done in different workspaces. I decided to run this approach to isolate
the issues and manage to fix them in no time.

In the end, by working with Gen AI, I have realised that it can enhance any user's ability, but what matters is the level
of that certain user in the scope of the project. Since I had some experience in Embedded projects and low-level programming,
it was easy for me to understand the issues really fast and find a solution. Some problems required a human review, and I provided
it with on-spot solutions.

---

## 10. Download

```markdown
TODO: Add links or attach:
- source code archive;
- schematic files;
- build instructions;
- README;
- ChangeLog;
- test logs;
- demo video;
- final presentation.
```
- The Schematic files can be found in the Mecha-Iepurele folder
- The _SWSide can be built and ran on an ESP-IDF environment. The _HWSide can be built on MCUXpresso environment.
- The Test cases and suites for checking the HW integrity can be used. Be sure to respect the pinout.

Demo video: `TODO`
Final Presentaion: `TODO`

---

## 11. Project Journal

| Date | Work Completed | Problems / Risks | Next Steps |
|---|---|---|---|
| 27-07-2026 | Components arrived | - | Planning Schematic |
| 06-08-2026 | Physical tests ran on standalone components | - | Soldering A and B channels (left and right wheels) |
| 17-08-2026 | Chassis Print and mounting it with the motors | - | Building the first level (motors + driver module + spot for battery |
| 20-08-2026 | Soldering first level done | The setup can't be tested in this state | Pulling the data signal wires from the driver module for testing |
| 23-08-2026 | Schematic Draft added | The pinout for the data signals may suffer changes | Testing initial pinout choices |
| 01-09-2026 | MCXA153 motor movement test | Risk removed, the motors work according to their channel | Movement definitions need to be added |
| 06-09-2026 | ESP32-S3 Nano microphone integration and STT | None | API call to LLM needs to be sent by using the specific transcript from STT |
| 09-09-2026 | README and documentation updated to match status | May not be final version | - |

---

## 12. Bibliography / Resources

### Hardware Resources

- TODO: FRDM-MCXA153 board documentation and schematic (`FRDM-MCXA153-Board-User-Manual.pdf`).
- TODO: MCXA153 datasheet and reference manual (`MCXA153-Reference-Manual.pdf`).
- TODO: RCWL-1601 / HC-SR04P 3.3V Ultrasonic Distance Sensor datasheet.
- TODO: TB6612FNG Dual H-Bridge Motor Driver datasheet.
- TODO: MAX98357A I2S 3.2W Class D Mono Amplifier datasheet.
- TODO: SG90 Micro Servo datasheet and PWM timing specifications.
- TODO: 2S LiPo battery safety guidelines, 2S BMS specs, and IP2326 / TP5100 balance charger datasheets.

### Software Resources

- TODO: NXP MCUXpresso SDK for MCXA153 documentation and API reference.
- TODO: MCUXpresso Config Tools (Pin Mux, Clock Tool, Peripheral Config).
- TODO: ESP32-S3 Arduino Core / ESP-IDF mbedTLS & HTTP Client documentation.
- TODO: Project GitHub repository and code release archives.

### Learning Resources

- Course/lab notes for Embedded Engineering and Gen AI Summer School: https://alexp25.github.io/ipcei-lab/
- Mechanical 3D printing guidelines for PETG and PLA materials. https://ultimaker.com/learn/petg-vs-pla-vs-abs-3d-printing-strength-comparison/

---

## 13. Documentation Status

`READY FOR HUMAN REVIEW`

- The project documentation draft cleanly integrates all Agent 0 scoping intent and Agent 1 engineering requirements into a structured, DokuWiki-aligned Markdown template.
- Mandatory hardware platform constraints (NXP FRDM-MCXA153 MCU board) and secondary coprocessor assignments (ESP32-S3 Nano) are strictly preserved and validated.
- All functional requirements, non-functional requirements, test plan cases, traceability matrix entries, and risk register items are completely detailed without missing tables.
- Organic status feedback (servo ear sweeps without status LEDs), hopping double-crank locomotion with 90-degree rotary kicks, active rear steering tail-skid, onboard USB-C 2S balance charging, and privacy data-wiping mechanisms are fully incorporated.
- Clear `TODO` placeholders and a Human Review Checklist are provided for student implementation and instructor sign-off.

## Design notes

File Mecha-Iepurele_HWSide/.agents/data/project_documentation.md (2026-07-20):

# Mecha-Iepurele (Mechanized Bunny)

**Author:** Alice Dobre
**Date:** 2026-07-20  

> Documentation draft generated from Agent 0 and Agent 1 outputs.  
> AI assists. Humans decide.

## 1. Introduction

Mecha-Iepurele (Mechanized Bunny) is an interactive, moving robotic companion designed for indoor flat surfaces (classroom, table, or smooth floor). The robot engages in natural conversations with humans via a cloud-based Conversational AI API and physically tracks and follows the user. High-level network operations (Wi-Fi connectivity, HTTPS API transactions, JSON payload parsing, and direct Text-to-Speech audio rendering via an I2S DAC) are offloaded to an ESP32 coprocessor suite (ESP32-S3 Nano), while low-level motor control loops, servo ear and eyelid movements, active steering, battery monitoring, and sensor processing are managed by the main microcontroller board.

The purpose of this project is to create an engaging physical robotic companion that bridges low-level embedded hardware (sensors, motor drivers, PWM actuators, power management) with cloud-based artificial intelligence. The project originated from a concept for a mechanized bunny that talks to users, mimics emotional expressions based on conversation mood, and follows the user.

This project is especially valuable for third-year Computer Science students participating in the Embedded Engineering and Gen AI Summer School, as it teaches core embedded concepts (UART communication, PWM signal generation, I2C/I2S interfacing, control loops, power isolation, and software debouncing) as well as networking, API parsing, privacy protection, and system integration.

The **NXP FRDM-MCXA153 board featuring the NXP MCXA153 MCU** is selected as the mandatory target controller for all summer school projects. It provides Arm Cortex-M33 real-time processing, low-power timer peripherals, LPUART interfaces, and ADC channels required for local actuator control and sensor processing.

> This documentation is a draft and must be validated by students and instructors before implementation.

---

## 2. General Description

### 2.1 Project Summary

- **Project Name:** Mecha-Iepurele (Mechanized Bunny)
- **Author / Student Team:** TODO: Add Student Author(s) Name(s) and Student ID(s)
- **Short Summary:** An interactive, moving mechanized bunny robot that communicates with a human via an AI API (over ESP32 Wi-Fi) and mimics emotional expressions using physical movement (ear sweeps and eyelid states).
- **Main Objective:** Build a robotic companion that uses a FRDM-MCXA153 board for local sensor-motor control and expressions, and an ESP32-S3 Nano for Wi-Fi connection to a cloud conversational AI API that provides responses and mood data.
- **Intended Users:** Third-year university Computer Science students and summer school reviewers/instructors.
- **Operating Environment:** Indoor flat surfaces (classroom, laboratory table, or smooth floor) with active Wi-Fi connectivity.
- **Selected Scope:** Recommended Summer School Version featuring mobile hopping locomotion via a single central DC motor driving a double-crank axle, active steering via a rear tail-skid servo, ear and eyelid expression servos, ultrasonic user tracking, direct I2S TTS voice output on the ESP32, and onboard USB-C 2S LiPo balance charging.
- **Main Behavior:** Upon boot, the bunny initializes peripherals and connects to Wi-Fi. When user conversation is triggered, the ESP32 queries the cloud AI API, receives text response and mood data, and streams TTS voice output through an I2S DAC/speaker. The ESP32 sends servo targets to the MCXA153 via UART (with ACK confirmation). The MCXA153 updates ear servos (drooping for sad, perking for happy) and eyelid state. Concurrently, a 50 ms motor control loop reads an ultrasonic sensor to track user distance (maintaining 30–50 cm) and drives the central hopping DC motor and steering tail-skid servo to follow the user smoothly.
- **Inputs:**
  - Ultrasonic distance sensor (RCWL-1601 / HC-SR04P, 3.3V compatible) measuring user distance.
  - Tactile physical buttons (setup / Wi-Fi provisioning / emergency stop).
  - Wi-Fi connection to Cloud LLM/NLP API (via ESP32-S3 Nano coprocessor).
  - Battery voltage diagnostic signal via resistor divider to ADC.
- **Outputs:**
  - 1x Central high-torque DC TT gear motor (via TB6612FNG H-bridge driver) for 90-degree kick hopping locomotion.
  - 4x SG90 Micro Servos (2x ears, 1x eyelids, 1x rear steering tail-skid).
  - MAX98357A I2S Audio DAC + 8 Ohm 2W speaker (driven directly by ESP32-S3 Nano).
  - Eyelids organic state feedback (open = awake, slow blink = Wi-Fi searching, closed = asleep/low battery).
- **Out-of-Scope Items:**
  - On-board execution of heavy Large Language Models (LLMs) or local Speech-to-Text on the MCXA153.
  - High-speed navigation on rough terrain or stairs.
  - Complex multi-obstacle collision avoidance beyond tracking the primary user.
  - Custom cloud backend hosting (standard pre-existing HTTP REST AI endpoints are assumed).
  - Status LEDs (all status feedback is expressed organically through physical ear and eyelid movements).
  - OLED screen displays and local web input pages (in the speech TTS direct-drive edition).

### 2.2 Feature Tiers

| Tier | Description | Main Features | Extra Components | Main Risks | Suitability |
|---|---|---|---|---|---|
| **Core** | Static Ear/Eyelid desktop prototype in shell | ESP32-S3 Nano Wi-Fi handshake, queries mock/REST API, direct TTS audio via I2S MAX98357A DAC, MCXA153 drives 2x ear servos and 1x eyelid servo, NVS data wiping, UART ACK comms | ESP32-S3 Nano, MAX98357A DAC + Speaker, 2x Ear Servos, 1x Eyelid Servo, 3D Printed Shell & Brackets | UART framing errors, Wi-Fi handshake timeout, API parsing failure | **High suitability:** Focuses on serial comms, basic GPIO, and PWM servo control. Realistic for early development. |
| **Recommended** | Mobile Speech Companion (Selected Target Scope) | All Core features plus differential hopping leg linkage (1x central DC TT motor + H-bridge) executing gentle 90-degree kicks, active steering rear tail-skid, ultrasonic distance tracking (30–50 cm window), 50 ms motor loop, battery ADC monitoring (<6.4V sleep), 2S LiPo balance charging via USB-C port, magnetic quick-release ventilated shell | 1x DC TT Motor, TB6612FNG Driver, 3.3V Ultrasonic Sensor, 2S LiPo Battery & BMS, 2S USB-C Balance Charger Module, 4x Servos (Ears, Eyelids, Steering), USB-C Panel Cable, MR85ZZ Bearings, PETG/TPU Filaments | Mechanical binding, leg joint wear, high component density heat, ground impact shock, battery over-discharge | **Good with guidance:** Combines PWM, control loops, mechanical kinematics, power isolation, and safety. Excellent depth. |
| **Advanced** | Voice-Input Speech Companion | All Recommended features plus local I2S MEMS microphone (INMP441) on ESP32-S3 Nano for voice command streaming, wake-word detection / TinyML keyword spotting, local fuel gauge | INMP441 I2S MEMS Mic, LiPo Fuel Gauge IC, Camera module (ESP32-CAM / HuskyLens) | Acoustic feedback loops, double-buffered I2S timing, high power draw, memory limits | **Low (Optional extension):** Suitable only as a capstone extension for advanced teams due to time limits. |

### 2.3 Scenarios

| ID | Scenario | Description |
|---|---|---|
| `SC-001` | Startup / Setup | Device powers on. MCXA153 initializes GPIOs, LPUART, ADC, and PWM timers. ESP32-S3 Nano reads Wi-Fi credentials from NVS and connects to Wi-Fi. Upon successful connection, ESP32 sends "Online" byte over UART. MCXA153 opens eyelids and sweeps ears to neutral to confirm awake state. |
| `SC-002` | Dynamic Wi-Fi Provisioning | If Wi-Fi fails within 15 seconds or setup button is held for 5 seconds at boot, ESP32 launches an Access Point setup portal. Eyelids blink slowly to indicate search state. User connects via smartphone, submits credentials, and ESP32 connects and opens eyelids. |
| `SC-003` | Multi-User Device Wiping | Tester A finishes testing. Tester A holds setup button for 10 seconds. ESP32 erases all stored Wi-Fi credentials, tokens, and caches from NVS, reboots, sweeps ears to neutral, and closes eyelids to sleep. |
| `SC-004` | Onboard Battery Charging | When battery drops below 6.4V, MCXA153 halts motors and closes eyelids. User plugs standard 5V USB-C cable into shell port. Integrated 2S balance charger charges cells to 8.4V. Eyelids remain closed during charging. |
| `SC-005` | Normal Operation & Speech Playback | Conversation is triggered. ESP32 queries Cloud AI REST API, receives JSON (response text, mood tag, servo angles), extracts servo targets, and requests TTS audio stream. ESP32 renders audio via I2S to MAX98357A DAC. Eyelids remain open. |
| `SC-006` | Active Privacy Cleansing | Speech playback completes. ESP32 immediately fills audio buffers and text RAM strings with zeros (`0x00`). Subsequent API calls use a newly generated, isolated session UUID to prevent user profiling. |
| `SC-007` | Actuator Expression Control | ESP32 sends parsed servo angles and mood data over LPUART to MCXA153. MCXA153 updates FTM/TPM PWM registers, driving ear servos to sweep to target angles (drooping for sad, perking for happy) while keeping eyelids open. |
| `SC-008` | Distance Sensor Processing | MCXA153 runs a periodic 50 ms motor loop. It triggers the ultrasonic sensor with a 10 us pulse, measures Echo pin return duration, and calculates distance in centimeters. |
| `SC-009` | Proximity Hopping & Steering | User is detected at 80 cm, offset right. MCXA153 drives central DC motor via PWM. Shared double-crank axle sweeps leg linkages past 90 degrees vertical, executing a gentle downward shove that hops chassis forward. Simultaneously, steering servo pivots rear tail-skid right for a smooth turn, slowing down as distance reaches 30–50 cm window. |
| `SC-010` | Safety & Reliability (Sleep Halt) | Emergency stop button is pressed, sensor Echo hangs >250 ms, or battery falls <6.4V. MCXA153 forces motor PWM to 0%, pulls motor driver STBY low, centers steering servo, droops ears, and closes eyelids to asleep state. |

### 2.4 User Stories

| ID | User Story |
|---|---|
| `US-001` | As a student developer, I need to use the NXP FRDM-MCXA153 board, so that the project complies with the course's mandatory hardware platform. |
| `US-002` | As a user, I need the bunny to dynamically connect to different Wi-Fi networks using a setup mode, so that I can easily bring the companion to new environments. |
| `US-003` | As a tester, I need to easily wipe my Wi-Fi credentials and conversation logs from the device, so that my personal network keys and private voice contents are not exposed to subsequent testers. |
| `US-004` | As a tester, I need the communication to be encrypted and my conversation session ID to be isolated, so that my conversations cannot be intercepted on local Wi-Fi or linked to other testers' profiles. |
| `US-005` | As a user, I need the bunny to convey its state of sleep and activity through physical movements of the ears and eyelids, so that it looks like an organic creature without unnatural flashing LEDs. |
| `US-006` | As a developer, I need to power the motors and microcontrollers from a single large LiPo battery with separate regulators, so that logic circuitry is fully isolated from motor transients. |
| `US-007` | As a user, I want the bunny to move by hopping like a real rabbit, utilizing a robust leg linkage system that avoids binding, joint wear, and synchronization failures. |
| `US-008` | As a builder, I need structural mounts and leg linkages printed with PETG filament and low-friction bearings, so that the hopping mechanism has high toughness and structural durability. |
| `US-009` | As a builder, I need a spacious ventilated body shell with magnetic latches, an onboard USB-C 2S balance charger, and a 2S BMS protection board, so that components fit safely and battery charging is convenient and safe. |
| `US-010` | As a student builder with a 7-week project timeline, I need pre-designed mechanical model templates (STL/STEP) to build from, or I must strictly limit custom Blender CAD learning and design to a maximum of 1 week. |
| `US-011` | As a user, I need the bunny to be able to take motion turns when necessary, so that it can steer around obstacles or track my position as I turn corners. |
| `US-013` | As a builder, I want a non-piston leg linkage that hops the whole body by rotating the leg to 90 degrees relative to the body, executing a gentle low-amplitude hop to keep the movement stable and protect components. |

### 2.5 Use Case Diagram

```mermaid
flowchart LR
    Student[Student Developer]
    User[User / Tester]
    Instructor[Instructor / Reviewer]

    UC1((Initialize System & Hardware))
    UC2((Provision Wi-Fi Credentials))
    UC3((Trigger Conversation Session))
    UC4((Query Cloud AI & Stream TTS))
    UC5((Animate Ear & Eyelid Expressions))
    UC6((Track User & Proportional Hop))
    UC7((Pivot Rear Steering Tail-Skid))
    UC8((Trigger Organic Sleep / Halt))
    UC9((Wipe Credentials & Clean RAM))
    UC10((Charge 2S LiPo via USB-C))
    UC11((Review Test Evidence & Code))

    Student --> UC1
    User --> UC2
    User --> UC3
    UC3 --> UC4
    UC4 --> UC5
    UC3 --> UC6
    UC6 --> UC7
    User --> UC8
    User --> UC9
    User --> UC10
    Instructor --> UC11
```

### 2.6 Hardware and Software Block Diagram

```mermaid
flowchart TD
    subgraph PowerSystem["Power Subsystem"]
        BAT["2S LiPo Battery (7.4V - 8.4V)"]
        BMS["2S BMS Protection Board (6.0V Cutoff)"]
        CHG["2S Balance Charger Module (IP2326/TP5100)"]
        USBC["Panel USB-C Port"]
        REG_LOGIC["3.3V / 5.0V Logic Regulator"]
        REG_MOTOR["5.0V / 6.0V Motor & Servo Regulator"]
        BATT_DIV["Resistor Voltage Divider (10k / 4.7k)"]

        USBC --> CHG
        CHG --> BMS
        BAT <--> BMS
        BMS --> REG_LOGIC
        BMS --> REG_MOTOR
        BMS --> BATT_DIV
    end

    subgraph ESP32Core["ESP32-S3 Nano Coprocessor"]
        WIFI["Wi-Fi 2.4GHz Engine"]
        REST["HTTPS Client & JSON Parser"]
        I2S_OUT["I2S Digital Audio Output"]
        NVS["NVS Storage (Credentials & Keys)"]
    end

    subgraph MCUCore["NXP FRDM-MCXA153 Main Controller"]
        LPUART["LPUART Interface (115200 8-N-1)"]
        PWM_TIMERS["FTM / TPM Timer PWM Generators"]
        GPIO_CTRL["GPIO Controllers"]
        ADC_CTRL["12-bit ADC Input"]
        SUPERLOOP["Superloop & State Machine Task"]
    end

    subgraph AudioOutput["Audio Output Subsystem"]
        DAC["MAX98357A I2S DAC Amplifier"]
        SPK["8 Ohm 2W Speaker"]
        DAC --> SPK
    end

    subgraph ActuatorsSensors["Sensors & Actuators"]
        US_SENS["Ultrasonic Distance Sensor (RCWL-1601)"]
        EAR_L["Left Ear Servo (SG90)"]
        EAR_R["Right Ear Servo (SG90)"]
        EYELID["Eyelid Servo (SG90)"]
        STEER["Rear Steering Servo (SG90)"]
        TB6612["TB6612FNG H-Bridge Motor Driver"]
        DCMOTOR["Central DC TT Gear Motor"]
        ESTOP["Emergency Stop / Setup Button"]
        LINKAGE["Double-Crank Hopping Leg Linkage (PETG)"]

        TB6612 --> DCMOTOR
        DCMOTOR --> LINKAGE
    end

    %% Power distribution flow
    REG_LOGIC -.->|3.3V Power| ESP32Core
    REG_LOGIC -.->|3.3V Power| MCUCore
    REG_LOGIC -.->|3.3V Power| US_SENS
    REG_MOTOR -.->|5V/6V Power| DAC
    REG_MOTOR -.->|5V/6V Power| EAR_L
    REG_MOTOR -.->|5V/6V Power| EAR_R
    REG_MOTOR -.->|5V/6V Power| EYELID
    REG_MOTOR -.->|5V/6V Power| STEER
    REG_MOTOR -.->|5V/6V Power| TB6612

    %% Inter-processor data flow
    ESP32Core <== LPUART ACK Protocol ==> MCUCore
    I2S_OUT ==> DAC

    %% MCU Control connections
    BATT_DIV --> ADC_CTRL
    US_SENS <== GPIO / Capture ==> MCUCore
    ESTOP --> GPIO_CTRL
    PWM_TIMERS --> EAR_L
    PWM_TIMERS --> EAR_R
    PWM_TIMERS --> EYELID
    PWM_TIMERS --> STEER
    PWM_TIMERS --> TB6612
    GPIO_CTRL --> TB6612
```

**System Architecture Explanations:**

- **Power Flow:** Power originates from a 2S LiPo battery pack (7.4V nominal, 8.4V max) connected through a 2S BMS protection board (6.0V cutoff). Power is split into two independent buck/LDO regulators: a digital logic regulator supplying 3.3V to the MCXA153, ESP32-S3 Nano, and ultrasonic sensor; and a motor/actuator regulator supplying 5.0V/6.0V to the TB6612FNG driver, MAX98357A DAC, and 4x SG90 servos. An onboard 2S USB-C balance charger (IP2326 or TP5100) charges the pack via a shell-mounted USB-C port.
- **Data & Control Flow:** The ESP32-S3 Nano executes Wi-Fi handshakes and cloud HTTPS transactions. Audio data streams directly over I2S to the MAX98357A DAC and speaker. Parsed servo targets, mood data, and system commands are sent to the MCXA153 over LPUART at 115200 baud. The MCXA153 validates checksums, returns software ACK bytes, updates servo PWM registers, and executes the 50 ms ultrasonic distance tracking loop to modulate the central DC motor and steering servo.
- **Compatibility Concerns:** MCXA153 GPIO pins operate strictly at 3.3V (max 4 mA per pin). Motor and servo power rails must never connect to MCU logic pins. A 3.3V-compatible ultrasonic sensor (RCWL-1601) is used, or a 10k/4.7k resistor divider is inserted on the Echo pin if using 5V HC-SR04 models. Battery voltage (up to 8.4V) is scaled down via a 10k/4.7k divider so the ADC receives <= 2.68V.
- **Protection & Decoupling:** Decoupling capacitors (100 uF electrolytic + 0.1 uF ceramic) are placed across power rails near the motor driver and servos to suppress inductive current spikes and prevent MCU brownouts. A freewheeling diode protection network is integrated inside the TB6612FNG driver.
- **Datasheet Checks Required:**
  - NXP MCXA153 reference manual: verify LPUART0 pin muxing, FTM/TPM timer channel assignments, and 12-bit ADC input channels.
  - TB6612FNG datasheet: check VM logic input ranges, logic VCC (3.3V), and STBY pin pull-down behavior.
  - MAX98357A datasheet: verify bit clock (BCLK), word select (LRCK), and serial data (SDIN) timing parameters for ESP32 I2S.
  - 2S BMS & Charger datasheets: confirm overcharge threshold (4.25V) and over-discharge threshold (3.0V per cell).

---

## 3. Hardware Design

### 3.1 Bill of Materials

| # | Component | Qty | Tier | Purpose | Likely Interface | Voltage / Power Notes | Risks / Checks |
|---|---:|---:|---|---|---|---|---|
| 1 | NXP FRDM-MCXA153 | 1 | Core | Central low-level MCU board for motor loop, PWM servos, ADC, and distance timing | LPUART, PWM, GPIO, ADC | 3.3 V Logic; Powered via USB-C or regulated 3.3V pin | Mandatory board. Verify pinout and 3.3V logic boundaries. |
| 2 | ESP32-S3 Nano | 1 | Core | Wi-Fi coprocessor, HTTPS API client, JSON parser, I2S audio renderer, NVS storage | LPUART, I2S, Wi-Fi | 3.3 V Logic; Powered via regulated 3.3V rail | Confirm NVS data wiping and 115200 baud UART link. |
| 3 | MAX98357A I2S DAC | 1 | Core | Direct digital audio decoding and amplification for voice TTS output | I2S (BCLK, LRCK, DIN) | Powered via 5V rail; 3.3V I2S logic from ESP32 | Audio noise from power ripples; route I2S away from UART. |
| 4 | Dynamic Speaker (8 Ohm, 2W) | 1 | Core | Voice TTS output speaker | Direct wire to DAC | Driven by MAX98357A DAC output | Ensure secure mounting inside head/body shell. |
| 5 | SG90 Micro Servos | 4 | Core / Rec | Physical actuators: 2x Ears, 1x Eyelids, 1x Rear Steering Tail-skid | FTM/TPM PWM (50 Hz) | 5V Power rail; 3.3V PWM control logic | Current spikes during stall can reset MCU; use dedicated 5V regulator. |
| 6 | High-Torque DC TT Gear Motor | 1 | Recommended | Drives shared double-crank axle for 90-degree kick hopping locomotion | PWM + 2x GPIO (TB6612) | Powered via 5V-6V motor regulator rail | Inductive noise spikes; require freewheeling diodes & decoupling. |
| 7 | TB6612FNG H-Bridge Motor Driver | 1 | Recommended | Controls speed and direction of central DC gear motor | PWM, 2x GPIO, STBY pin | VM 5V-6V, VCC 3.3V logic | Verify STBY pin default low for safe shutdown. |
| 8 | Ultrasonic Distance Sensor (RCWL-1601) | 1 | Recommended | Measures distance to user (30-50 cm window) for proportional following | GPIO Trigger / Echo Capture | 3.3V Power & Logic | Sensor timeout hang; software 250ms watchdog required. |
| 9 | 2S LiPo Battery Pack (7.4V, 1500+ mAh) | 1 | Recommended | Main power source for mobile robot | 2S JST-XH balance + XT30/T-plug | 7.4V nominal (8.4V max, 6.0V cutoff) | Fire / thermal hazard; requires BMS board & balance charger. |
| 10 | Dual Buck / LDO Regulators | 2 | Recommended | Independent voltage regulation: 1x 3.3V logic, 1x 5V/6V motor & servos | Power rails | Input 7.4V; Output 3.3V and 5.0V | Heat dissipation; check continuous current ratings (>= 2A for motor rail). |
| 11 | 2S USB-C Balance Charger Module (IP2326/TP5100) | 1 | Recommended | Onboard USB-C balance charging for 2S battery pack | USB-C input, 2S balance output | Input 5V USB-C; Output 8.4V balance charge | Verify auto cut-off at 8.4V. |
| 12 | 2S LiPo BMS Protection Board | 1 | Recommended | Battery safety cutoff (overcharge, over-discharge, overcurrent) | Series battery connection | Cutoff at 6.0V overall pack voltage | Verify overcurrent protection >= 4A. |
| 13 | USB-C Panel Mount Extension Cable | 1 | Recommended | Exposes charging port to outer body shell | USB-C | 5V 2A pass-through | Ensure solid mounting on shell exterior. |
| 14 | MR85ZZ Ball Bearings | 8-12 | Recommended | Low-friction pivot bearings for double-crank leg linkages | Mechanical press-fit | N/A | Prevents mechanical binding and motor stalls. |
| 15 | Neodymium Magnets (4x2 mm) | 8-12 | Recommended | Toolless quick-release magnetic latches for outer body shell | Mechanical recess | N/A | Allows instant access to debugger and internal electronics. |
| 16 | M3 Socket Fastener Kit | 1 pack | Core / Rec | Structural assembly screws, nylon locknuts, and washers | Mechanical | N/A | Ensure nylon locknuts prevent loosening during hopping. |
| 17 | Tactile Push Buttons | 2 | Core / Rec | Setup / Wi-Fi provisioning button & Emergency Stop button | GPIO with internal pull-up | 3.3V Logic | Software debouncing required (20 ms window). |
| 18 | PETG 3D Filament | ~300g | Recommended | Structural mounts, crank arms, steering brackets, leg links | 3D Printed | N/A | High impact toughness required for hopping landing stress. |
| 19 | TPU 3D Filament | ~100g | Recommended | Flexible feet landing pads and shock absorbers | 3D Printed | N/A | Shore hardness ~95A for ground traction and shock damping. |
| 20 | PLA 3D Filament | ~300g | Recommended | Spacious outer body shell (~180x120x120 mm) with ventilation grilles | 3D Printed | N/A | Non-stress enclosure. Sourced STL files recommended. |

### 3.2 Hardware Block Diagram Description

The Mecha-Iepurele hardware architecture is organized around a dual-processor design to isolate real-time motor and sensor control from network latency:

- **Main Controller (NXP FRDM-MCXA153):** Serves as the central low-level executive. It runs a deterministic 50 ms superloop that handles PWM generation for 4x SG90 servos (left ear, right ear, eyelids, rear steering tail-skid), PWM speed and direction control for the central DC motor via the TB6612FNG H-bridge, GPIO pulse timing for the ultrasonic distance sensor, ADC voltage sampling for battery diagnostic monitoring, and UART packet parsing with ACK generation.
- **Coprocessor (ESP32-S3 Nano):** Manages all high-level Wi-Fi communications, TLS encryption, REST API transactions with the cloud AI endpoint, JSON response extraction, NVS credential storage/wiping, and direct I2S digital audio decoding to the MAX98357A DAC.
- **Power Architecture:** Powered by a single 2S LiPo battery pack (7.4V nominal, 8.4V max). Safety boundaries are enforced by a 2S BMS protection board that disconnects power if overall pack voltage drops to 6.0V (3.0V per cell) or current exceeds 4A. Two independent voltage regulators are fed from the BMS output: a 3.3V logic regulator powers the MCXA153, ESP32-S3 Nano, and ultrasonic sensor; a separate 5.0V/6.0V high-current regulator powers the TB6612FNG motor driver, 4x SG90 servos, and MAX98357A audio DAC. Battery voltage is monitored via a 10k / 4.7k resistor voltage divider connected to an ADC pin on the MCXA153 (delivering <= 2.68V at fully charged 8.4V). Onboard balance charging is achieved via an IP2326 or TP5100 2S balance charger module connected to a panel-mounted USB-C port on the outer shell.
- **Sensors & Actuators:**
  - *Ultrasonic Distance Sensor:* RCWL-1601 (3.3V native) mounted on the front chest/head to measure user distance.
  - *Hopping Locomotion:* 1x central DC TT gear motor drives a shared double-crank axle. Left and right leg linkages are physically locked in phase to the axle, preventing tipping. The leg linkages act as rotary levers; when sweeping through the 90-degree vertical angle relative to the chassis, they execute a gentle downward shove against the ground, lifting the body 5–15 mm into a forward hop/scoot. MR85ZZ ball bearings at all pivot joints minimize friction, while TPU pads on the feet absorb landing shock.
  - *Active Steering:* An SG90 micro servo pivots a rear tail-skid or caster assembly left/right by +/-30 degrees to steer the robot dynamically during hopping.
  - *Organic Expression Actuators:* 2x SG90 servos sweep the ears (drooped = sad, perked = happy/listening, neutral = idle); 1x SG90 servo opens and closes physical eyelids to reflect wakefulness, Wi-Fi searching (slow blink), and sleep state (fully closed). Status LEDs are completely omitted.
- **Protection & Compatibility:** Logic connections between 3.3V MCU pins and 5V components use resistor dividers or 3.3V native modules. Decoupling capacitors (100 uF electrolytic + 0.1 uF ceramic) buffer voltage dips near the motor driver and servos. Datasheet reviews must verify pin mux assignments in MCUXpresso Config Tool, LPUART baud rate clocks, and ADC reference voltage calibration.

### 3.3 Pin Allocation Draft

Generic FRDM-MCXA153 capability only - exact pin requires board pinout and datasheet verification.

| Component | Tier | Signal | Required MCU Capability | Suggested Pin / Capability | Voltage Level | Direction | Interface | Verification Needed |
|---|---|---|---|---|---|---|---|---|
| ESP32-S3 Nano | Core | UART_TX | LPUART RX input | Generic LPUART0_RX | 3.3 V | Input | UART (115200) | Confirm configuration matches LPUART peripheral routing in MCUXpresso Pin Mux tool. |
| ESP32-S3 Nano | Core | UART_RX | LPUART TX output | Generic LPUART0_TX | 3.3 V | Output | UART (115200) | Verify TX buffer is set to push-pull drive and baud rate clock is accurate. |
| Battery Sense | Rec | BATT_VSENSE | ADC Analog Input | Generic ADC Channel | <= 2.68 V | Input | Analog ADC | Verify 10k/4.7k resistor divider output does not exceed 3.3V at 8.4V max battery charge. |
| Left Ear Servo | Core | SERVO_PWM_L | Timer PWM output (FTM/TPM) | Generic PWM Channel 0 | 3.3V Logic / 5V Power | Output | PWM (50 Hz) | Scope PWM pulse widths (1.0 - 2.0 ms) under load; confirm 20 ms period. |
| Right Ear Servo | Core | SERVO_PWM_R | Timer PWM output (FTM/TPM) | Generic PWM Channel 1 | 3.3V Logic / 5V Power | Output | PWM (50 Hz) | Verify servo operates smoothly without causing MCU brownouts. |
| Eyelid Servo | Core | SERVO_PWM_EYELID | Timer PWM output (FTM/TPM) | Generic PWM Channel 4 | 3.3V Logic / 5V Power | Output | PWM (50 Hz) | Verify PWM controls open (awake), slow blink (search), and closed (sleep) profiles cleanly. |
| Steering Servo | Rec | SERVO_PWM_STEER | Timer PWM output (FTM/TPM) | Generic PWM Channel 5 | 3.3V Logic / 5V Power | Output | PWM (50 Hz) | Verify PWM controls rear tail-skid steering angle (+/-30 degrees) without binding. |
| Motor Driver (TB6612) | Rec | MOTOR_PWM | Timer PWM output (FTM/TPM) | Generic PWM Channel 2 | 3.3 V | Output | PWM (10 kHz) | Verify speed modulation carrier frequency of central DC TT motor. |
| Motor Driver (TB6612) | Rec | MOTOR_DIR1 | GPIO Output | Generic GPIO pin | 3.3 V | Output | GPIO | Check forward/reverse direction transitions. |
| Motor Driver (TB6612) | Rec | MOTOR_DIR2 | GPIO Output | Generic GPIO pin | 3.3 V | Output | GPIO | Verify complementary logic state to DIR1. |
| Motor Driver (TB6612) | Rec | STBY | GPIO Output | Generic GPIO pin | 3.3 V | Output | GPIO | Verify internal/external pull-down puts motor driver in standby on reset/fault. |
| Ultrasonic Sensor | Rec | TRIG | GPIO Output | Generic GPIO pin | 3.3 V | Output | GPIO Pulse | Confirm 10 us trigger pulse duration accuracy via SysTick/timer. |
| Ultrasonic Sensor | Rec | ECHO | GPIO Input Capture / Interrupt | Generic Input Capture pin | 3.3 V (level-shifted) | Input | Pulse Width | Verify level shifting / 3.3V sensor compatibility on Echo pulse return line. |
| Emergency Stop | Rec | STOP_BTN | GPIO Input with Pull-up | Generic Interrupt GPIO | 3.3 V | Input | GPIO (Interrupt) | Verify internal pull-up resistor and software debouncing (20 ms window). |
| Setup / Provisioning | Core | SETUP_BTN | GPIO Input with Pull-up | Generic Interrupt GPIO | 3.3 V | Input | GPIO (Interrupt) | Verify 5s hold launches AP mode and 10s hold formats NVS storage. |

*Note: All I2S connections (BCLK, LRCK, DIN) to the MAX98357A DAC are routed directly from the ESP32-S3 Nano GPIO pins and are not connected to the MCXA153.*

### 3.4 Electrical Schematics

- `TODO: Add final schematic image or link.`
- `TODO: Add motor driver wiring diagram.`
- `TODO: Add sensor connection diagram.`
- `TODO: Add power distribution diagram.`

### 3.5 Signal Diagrams and Measurements

- `TODO: Add PWM signal capture oscilloscope trace (50 Hz servo & 10 kHz motor PWM).`
- `TODO: Add ultrasonic sensor Trigger and Echo signal capture.`
- `TODO: Add LPUART serial debug capture showing ACK packet transmission.`
- `TODO: Add power rail voltage measurement during motor startup and leg kick.`
- `TODO: Add total current measurement during hopping locomotion and speech output.`
- `TODO: Add timing analysis plot for the 50 ms motor loop and UART responsiveness.`

---

## 4. Software Design

### 4.1 Development Environment

- **Target Microcontroller:** NXP MCXA153 (Arm Cortex-M33) on FRDM-MCXA153 development board.
- **Coprocessor:** ESP32-S3 Nano (Dual-core Xtensa LX7).
- **IDE & Toolchain:** MCUXpresso VS Code Edition or MCUXpresso IDE.
- **SDK & Software Framework:** NXP MCUXpresso SDK for MCXA153 (`fsl_lpuart`, `fsl_gpio`, `fsl_tpm`/`fsl_ftm`, `fsl_adc16`, `fsl_clock`).
- **ESP32 Toolchain:** ESP-IDF or Arduino IDE with ESP32 board support package (handling Wi-Fi, mbedTLS, HTTP client, cJSON, and I2S driver).
- **Programming Language:** C (C99 standard).
- **Debugging Hardware:** On-board MCU-Link / SWD (Serial Wire Debug) debugger and USB-UART serial logging.

If development tools are unresolved, consult: `TODO: Confirm exact development environment, SDK version, build system, and flashing/debugging workflow.`

### 4.2 Firmware Architecture

- **Architecture Style:** Dual-processor asynchronous model. The MCXA153 executes a bare-metal superloop with periodic timer tasks, while the ESP32-S3 Nano handles event-driven networking and audio tasks.
- **Reason for Choice:** Separates real-time sensor processing and motor/servo timing on the MCXA153 from network latency, SSL handshakes, and audio buffering on the ESP32.
- **Main Firmware Modules (MCXA153):**
  - `main.c`: Superloop coordination, state machine management, and SysTick scheduler.
  - `uart_comm.c`: LPUART driver, RX frame buffer, CRC checksum validation, and ACK packet transmission.
  - `motor_driver.c`: TB6612FNG H-bridge direction and PWM speed control for central DC TT motor.
  - `servo_ears.c`: PWM angle generation (50 Hz) for left and right ear expression servos.
  - `eyelid_control.c`: PWM generation (50 Hz) for organic eyelid state feedback (awake, search blink, sleep closed).
  - `steering_control.c`: PWM angle control (50 Hz) for rear tail-skid steering servo (+/-30 degrees).
  - `ultrasonic.c`: Trigger pulse generation and Echo input capture for distance measurement.
  - `battery_adc.c`: ADC 12-bit voltage sampling and under-voltage threshold check (<6.4V).
- **Startup Sequence:**
  1. Disable global interrupts.
  2. Configure system clocks to 48 MHz core frequency.
  3. Initialize GPIO ports, enabling internal pull-ups for buttons and default low states for motor driver STBY.
  4. Initialize LPUART0 peripheral (115200 baud, 8-N-1) and enable RX interrupts.
  5. Initialize FTM/TPM timers: TPM0 for motor PWM (10 kHz), TPM1 for ear, eyelid, and steering servos (50 Hz).
  6. Initialize ADC peripheral (12-bit) and calibrate battery voltage channel.
  7. Configure SysTick timer for 1 ms tick interrupts.
  8. Enable global interrupts.
  9. Poll for ESP32 online handshake byte; upon receipt, sweep ears to neutral and fully open eyelids.
- **Main Loop / Task Flow (50 ms Loop):**
  - *Task 1 (LPUART Frame Check):* Parse incoming bytes from ESP32. If CRC is valid, send ACK byte (`0x06`) and update ear/eyelid servo targets.
  - *Task 2 (Distance Tracking & Motor Control):* Trigger ultrasonic pulse, capture Echo width, and calculate distance. If Echo hangs >250 ms, enter safe shutdown. If distance is valid, compute error against 30–50 cm target window, adjust central DC motor PWM duty cycle and rear steering angle.
  - *Task 3 (Battery Check):* Sample battery ADC. If V < 6.4V, halt motor, droop ears, center steering, and close eyelids to sleep.
  - *Task 4 (Watchdog Feed):* Refresh coprocessor watchdog timer.
- **Error Handling & Safe-State Strategy:**
  If UART communication drops for >3.0 s, battery voltage falls <6.4V, ultrasonic Echo hangs >250 ms, or emergency stop is pressed, the MCU immediately transitions to `SAFE_SHUTDOWN`. Central motor PWM is forced to 0%, motor driver STBY is pulled low, steering servo is centered, ears are drooped, and eyelids are closed completely (organic sleep state).
- **Configuration Constants:**
  - `BAUD_RATE`: 115200
  - `SERVO_PWM_FREQ_HZ`: 50
  - `MOTOR_PWM_FREQ_HZ`: 10000
  - `TARGET_DIST_MIN_CM`: 30 (AI Assumption)
  - `TARGET_DIST_MAX_CM`: 50 (AI Assumption)
  - `BATTERY_LOW_CUTOFF_V`: 6.4 (AI Assumption)
  - `UART_TIMEOUT_MS`: 3000 (AI Assumption)
  - `SENSOR_TIMEOUT_MS`: 250 (AI Assumption)

### 4.3 Main Algorithms and Data Structures

- **State Machine:** Enums defining system states: `STATE_INIT`, `STATE_WIFI_PROVISION`, `STATE_IDLE_AWAKE`, `STATE_CONVERSING`, `STATE_TRACKING_HOP`, `STATE_LOW_BATTERY`, `STATE_SAFE_SHUTDOWN`.
- **Proportional Distance Control Algorithm:**
  ```text
  distance = read_ultrasonic_cm()
  if (distance > TARGET_DIST_MAX_CM) {
      error = distance - TARGET_DIST_MAX_CM
      motor_speed = clamp(BASE_SPEED + Kp * error, MIN_SPEED, MAX_SPEED)
      set_motor_direction(FORWARD)
  } else if (distance < TARGET_DIST_MIN_CM) {
      error = TARGET_DIST_MIN_CM - distance
      motor_speed = clamp(BASE_SPEED + Kp * error, MIN_SPEED, MAX_SPEED)
      set_motor_direction(REVERSE)
  } else {
      motor_speed = 0
      set_motor_direction(STOP)
  }
  ```
- **Steering Control Algorithm:** Adjusts rear tail-skid servo angle based on relative obstacle position or steering command offset (+/-30 degrees relative to center).
- **UART Frame Data Structure:**
  ```c
  typedef struct {
      uint8_t header;       // 0xAA
      uint8_t cmd_type;     // 0x01 = Servo update, 0x02 = Mood, 0x03 = Status
      int8_t  ear_left_deg; // Angle 0 - 180
      int8_t  ear_right_deg;// Angle 0 - 180
      uint8_t eyelid_state; // 0 = Closed, 1 = Open, 2 = Blink
      int8_t  steer_deg;    // Steering offset -30 to +30
      uint8_t crc8;         // Checksum
  } uart_payload_t;
  ```
- **Privacy Buffer Zero-Fill Routine:**
  Immediately after TTS playback completes on the ESP32, `memset(audio_buffer, 0, sizeof(audio_buffer))` and `memset(text_buffer, 0, sizeof(text_buffer))` are called to overwrite sensitive conversation contents in RAM.

### 4.4 Functional Requirements Summary

| ID | Tier | Requirement | Priority | Verification | Acceptance Criterion |
|---|---|---|---|---|---|
| `FR-001` | Core | The system shall use the NXP FRDM-MCXA153 board as the main controller for low-level sensor-motor control and real-time execution. | Must | Inspection | BOM confirms MCXA153 handles low-level actuator drive and real-time loop tasks. |
| `FR-002` | Core | The system shall use the ESP32-S3 Nano as the Wi-Fi, API, and audio parsing coprocessor. | Must | Inspection | Physical board layout includes the ESP32-S3 Nano connected to the MCXA153. |
| `FR-003` | Core | Upon power-on, MCXA153 shall initialize GPIOs, LPUART, ADC, and PWM timers, sweep ears to neutral, and open eyelids to confirm awake state. | Must | Test | Debug port outputs boot diagnostics; eyelids open and ears sweep to neutral. |
| `FR-004` | Core | The ESP32-S3 Nano shall perform a Wi-Fi handshake to connect to a local AP using credentials stored in NVS upon boot. | Must | Test | ESP32 logs show successful Wi-Fi connection using stored credentials. |
| `FR-005` | Core | ESP32-S3 Nano shall make HTTPS requests to the cloud AI API, parse JSON response, and extract servo angles and mood parameters. | Must | Test | JSON parser extracts data correctly from simulated API responses. |
| `FR-006` | Core | ESP32-S3 Nano shall directly parse and play back voice audio via I2S to MAX98357A DAC. No audio data shall be sent to MCXA153. | Must | Demo | Voice response is audible from speaker. Scope confirms no audio frames on UART link. |
| `FR-007` | Core | ESP32-S3 Nano shall transmit parsed servo and status parameters to MCXA153 over LPUART at 115200 baud, 8-N-1 formatting. | Must | Test | MCXA153 receives and parses UART commands containing correct angle targets. |
| `FR-008` | Core | MCXA153 shall actuate two SG90 ear servos using 50 Hz PWM signals to angles received from ESP32-S3 Nano. | Must | Demo | Ears move to commanded angles +/- 5 degrees. |
| `FR-009` | Rec | MCXA153 shall drive central DC TT motor via PWM (speed) and GPIO (direction) using TB6612FNG driver to actuate hopping double-crank axle. | Must | Test | PWM duty cycle and GPIO logic transition correctly matching motion commands. |
| `FR-010` | Rec | MCXA153 shall measure user distance in cm by triggering ultrasonic sensor and timing Echo pulse via GPIO capture. | Must | Test | Distance values resolve accurately within 2 cm to 150 cm window (+/- 2 cm tolerance). |
| `FR-011` | Rec | MCXA153 shall run a proportional control loop to drive central DC motor, keeping user within 30–50 cm window (AI Assumption). | Must | Demo | Robot hops forward when dist > 50cm, hops reverse when dist < 30cm, stops inside 30-50cm. |
| `FR-012` | Rec | MCXA153 shall monitor battery voltage via ADC divider. If V < 6.4V, disable motor, droop ears, and close eyelids to sleep. | Must | Test | At V < 6.4V, motor stops, ears droop, and eyelids close completely. |
| `FR-013` | Rec | Emergency stop button press shall force motor PWM to 0%, pull motor driver STBY low, center steering, and close eyelids to sleep. | Must | Test | Button press halts legs within 50 ms, centers steering, and closes eyelids. |
| `FR-014` | Core | If UART comms with ESP32 drops > 3.0 s (AI Assumption), MCXA153 shall stop motor, center steering, and close eyelids to sleep. | Must | Test | Disconnecting UART wire forces motor stop, steering centering, and eyelid closure within 3.5s. |
| `FR-015` | Rec | MCXA153 shall transmit a software ACK packet back to ESP32 upon successful receipt and CRC check of UART message. | Must | Test | ESP32 registers valid ACK byte within 100 ms of transmitting control frame. |
| `FR-016` | Rec | If ultrasonic Echo hangs > 250 ms (AI Assumption), MCXA153 shall stop motor, center steering, droop ears, and close eyelids. | Must | Test | Disconnecting Echo pin triggers motor stop, steering center, and eyelid closure in <= 250 ms. |
| `FR-017` | Rec | If ESP32 fails Wi-Fi within 15s or setup button held 5s, launch setup AP portal to save new Wi-Fi credentials to NVS. | Must | Test | Setup AP launches, accepts web credentials, and successfully saves them to NVS. |
| `FR-018` | Core | Holding setup button 10s at boot shall wipe all saved Wi-Fi credentials and tokens from NVS, close eyelids, and reboot. | Must | Test | Holding button 10s clears all stored credentials, verified by NVS check after reboot. |
| `FR-019` | Core | ESP32-S3 Nano shall generate a new random UUID session key upon boot/reset, preventing API conversation profile linking. | Must | Test | HTTP payloads show distinct, non-linked session UUIDs across boots and resets. |
| `FR-020` | Core | System shall overwrite all conversation text buffers and audio memory in RAM with zeros immediately after TTS speech completes. | Must | Test | Memory inspection confirms response text is overwritten in RAM immediately post-speech. |
| `FR-021` | Core | MCXA153 shall drive eyelid micro servo via 50 Hz PWM to open/close eyelids, conveying awake, searching, and sleep states. | Must | Demo | Eyelids open on boot, blink slowly during AP setup, and close fully on low battery or fault. |
| `FR-022` | Rec | Mechanical leg linkages shall be driven by 1x central DC TT motor rotating a shared double-crank axle to lock left/right leg phase. | Must | Inspection | Both leg drive cranks are physically pinned and locked in phase to the same motor axle. |
| `FR-023` | Rec | Power subsystem shall incorporate an onboard 2S balance charger connected to a USB-C shell port to charge battery without shell disassembly. | Must | Test | USB power delivery is negotiated; onboard charger balances and charges cells to 8.4V. |
| `FR-024` | Rec | Outer 3D printed shell shall have a spacious design (~180x120x120 mm) with airflow grilles and magnetic quick-release latches. | Must | Inspection | Shell houses all components without wire pinching, provides vents, and opens toollessly. |
| `FR-025` | Rec | MCXA153 shall actuate a steering micro servo (SG90) via 50 Hz PWM to pivot rear tail-skid +/-30 degrees for hopping turns. | Must | Test | Steering servo moves to target angles on command; tail-skid turns chassis dynamically. |
| `FR-026` | Rec | Leg linkages shall sweep through 90 degrees vertical, executing a gentle downward kick that lifts body 5-15 mm for a stable hop. | Must | Test | Continuous motor rotation sweeps legs past 90 degrees, lifting chassis off floor during kick. |

### 4.5 Non-Functional Requirements Summary

| ID | Tier | Category | Requirement | Metric / Threshold | Verification |
|---|---|---|---|---|---|
| `NFR-001` | Core | Safety / Electrical | All components connected to MCXA153 must be 3.3V logic compatible. Status feedback must not use LEDs. | GPIO V <= 3.3V; Current <= 4 mA/pin. Status conveyed via ear/eyelids organically. Zero LEDs. | Inspection / Scope measurement |
| `NFR-002` | Core | Memory | Static RAM utilization of MCXA153 firmware must stay within MCU memory limits. | SRAM usage <= 28 KB (leaving 4 KB safety margin). (AI Assumption) | Compiler map file analysis (.map) |
| `NFR-003` | Rec | Power Isolation | Power MCU/ESP32 logic and motor via independent voltage regulators from shared 2S battery pack. | Regulated 3.3V logic, regulated 5V/6V motor; 10k/4.7k divider scales ADC <= 2.68V. | Inspection / Voltmeter measurement |
| `NFR-004` | Rec | Mechanical Filaments | Structural mounts and leg links printed strictly in PETG; joints use MR85ZZ bearings; feet use TPU. | Links: PETG; Feet: TPU; Shell: PLA; Bearings: MR85ZZ at all pivot pins. | Physical inspection / Filament spec audit |
| `NFR-005` | Rec | Timing | Motor control user-following loop must run at a deterministic periodic rate to prevent lag. | Control loop period 50 ms +/- 5 ms. (AI Assumption) | Test (GPIO toggle & logic analyzer trace) |
| `NFR-006` | Rec | Safety | If distance sensor readings hang or fail, system must immediately disable motor and close eyelids. | Stop motor and close eyelids within <= 100 ms of invalid sensor reading. (AI Assumption) | Test (pulling sensor pin / simulating fault) |
| `NFR-007` | Core | Wi-Fi Connection | ESP32 shall establish Wi-Fi link within a defined startup window before indicating search state. | Wi-Fi handshake timeout <= 15 seconds. (AI Assumption) | Test (forcing connection failures & timing) |
| `NFR-008` | Core | Privacy / Security | System shall encrypt all API network transactions to prevent conversation eavesdropping. | Enforce TLS 1.2 or higher for all HTTPS calls from ESP32. | Wireshark network packet sniffing |
| `NFR-009` | Advanced | Privacy / Security | Microphone must not record passively; active recording must require physical trigger button. | Recording starts only on button press. Active state shown via ear/eyelid gestures (No LEDs). | Demonstration / Functional audit |
| `NFR-010` | Rec | Battery Safety | Battery power circuit must include an integrated 2S BMS board enforcing safety protection boundaries. | Cell overcharge 4.25V; over-discharge cutoff 3.0V (6.0V pack); overcurrent >= 4A. | Short-circuit & load test verification |
| `NFR-011` | Rec | CAD Sourcing & Timeline | Sourcing pre-designed STL/STEP models is highly recommended. Limit CAD design to max 1 week. | CAD learning & design phase <= 1 week of 7-week timeline. 100% files sourced/done. | Audit of file availability & project log |

### 4.6 Test Plan Summary

| Test ID | Requirement | Tier | Test Type | Expected Result | Evidence |
|---|---|---|---|---|---|
| `TC-001` | `FR-001` | Core | Inspection | Target controller is confirmed as NXP FRDM-MCXA153. Secondary coprocessors allowed. | Physical board photo & BOM inspection. |
| `TC-002` | `FR-003`, `FR-021` | Core | Test | Apply power; MCU boots, prints init log to serial console, and opens eyelids within 1.0 s. | Diagnostic console log & video of eyelid open. |
| `TC-003` | `FR-007` | Core | Test | Connect ESP32 and MCXA153 UART lines; send test frames for 5 minutes. | Zero byte corruption / framing errors. Logic analyzer capture. |
| `TC-004` | `FR-005` | Core | Test | Send mock JSON payload to ESP32; monitor parser output. | JSON parser extracts servo angles and mood variables correctly. ESP32 serial logs. |
| `TC-005` | `FR-006` | Core | Test | Trigger audio playback on ESP32 connected to MAX98357A DAC. | DAC receives direct digital I2S frames and drives speaker smoothly. Audio waveform trace. |
| `TC-006` | `FR-006` | Core | Demo | Stream voice response to ESP32; measure audio loudness. | Voice response is clearly audible (sound level >= 70 dBA at 1 meter). Audio recording. |
| `TC-007` | `FR-014`, `FR-021` | Core | Test | Disconnect LPUART RX wire from MCXA153 during operation. | Motor stops, steering centers, and eyelids close completely within 3.5 seconds. Timing capture log / video check. |
| `TC-008` | `FR-009` | Rec | Test | Suspend chassis; inject forward drive commands to central DC motor. | Motor spins; double-crank axle rotates smoothly without binding (current <= 300 mA). Current measurement log. |
| `TC-009` | `FR-010` | Rec | Test | Place obstacle at 50 cm distance from ultrasonic sensor. | Calculated distance displays as 50 cm +/- 2 cm. Tape measure vs debug log comparison. |
| `TC-010` | `FR-011`, `FR-022`, `FR-025` | Rec | Demo | Place robot on floor; move obstacle to 80cm then 20cm; send turn command. | Robot hops forward, steers tail-skid left/right, and maintains 30-50 cm window. Video of hopping turns. |
| `TC-011` | `FR-008` | Core | Demo | Send servo angle command for 45 degrees (drooped ears). | Ear servos sweep to 45 degrees; PWM pulse width measures 1.25 ms. Scope pulse width trace. |
| `TC-012` | `FR-012`, `FR-021` | Rec | Test | Drop battery source voltage below 6.4 V. | Motor disables immediately, ears droop, steering centers, and eyelids close. Multimeter check & video log. |
| `TC-013` | `FR-013`, `FR-021` | Rec | Test | Actuate motors at full speed; press Emergency Stop button. | DC motor PWM drops to 0%, steering centers, and eyelids close in <= 50 ms. Logic analyzer capture / video. |
| `TC-014` | `FR-015` | Rec | Test | Send UART packet from ESP32 to MCXA153; measure time to receive ACK. | MCXA153 returns ACK byte (`0x06`); ESP32 receives it in <= 100 ms. Logic analyzer trace. |
| `TC-015` | `FR-016`, `FR-021` | Rec | Test | Cut ultrasonic sensor Echo wire while robot is moving. | Safe shutdown task halts motor, centers steering, and closes eyelids within 250 ms. Debug log showing halt time. |
| `TC-016` | `FR-017`, `FR-021` | Rec | Test | Force Wi-Fi connection failure; submit credentials via setup AP portal. | Eyelids blink slowly during search; setup portal saves keys to NVS; eyelids open wide on connect. NVS dump & connection logs. |
| `TC-017` | `FR-018` | Core | Test | Hold setup button for 10 seconds at boot; inspect NVS memory. | Stored Wi-Fi keys and session caches are formatted/erased. NVS check post-reboot. |
| `TC-018` | `FR-020` | Core | Test | Complete TTS voice response; inspect ESP32 RAM buffers post-speech. | RAM memory addresses for text strings contain `0x00` zero-fill. Memory debugger dump. |
| `TC-019` | `FR-023` | Rec | Test | Connect 5V USB-C source to shell port with depleted battery (V < 7.0V). | Onboard balance charger negotiates power, balances cells, and stops at 8.4V +/- 0.05V. Charger status log / Voltmeter. |
| `TC-020` | `FR-025` | Rec | Test | Send steering angles (+30 deg, 0 deg, -30 deg) over UART. | Rear steering tail-skid rotates to target angle +/- 2 degrees without binding. Protractor measurement & video. |
| `TC-021` | `FR-026` | Rec | Test | Power central DC motor; capture leg linkage sweep in slow motion. | Legs sweep past 90 degrees vertical, delivering a downward push that lifts chassis 5-15 mm off floor. Slow-motion video review. |

### 4.7 Traceability Summary

| User Story | Requirement(s) | Test Case(s) | Evidence | Gap |
|---|---|---|---|---|
| `US-001` (Mandatory Board) | `FR-001` | `TC-001` | Physical board label photo & BOM inspection | None |
| `US-002` (Wi-Fi Portability) | `FR-002`, `FR-004`, `FR-017`, `NFR-007` | `TC-016` | AP setup portal screenshots & connection logs | None |
| `US-003` (Data Wiping & Privacy) | `FR-018`, `FR-020` | `TC-017`, `TC-018` | NVS post-wipe state check & RAM zero-fill debugger dump | None |
| `US-004` (Encrypted Comm) | `FR-019`, `NFR-008` | Network Sniffing Check | Wireshark TLS 1.2 validation & HTTP UUID capture | None |
| `US-005` (Organic Eyelid Feedback) | `FR-003`, `FR-008`, `FR-012`, `FR-013`, `FR-014`, `FR-016`, `FR-021`, `NFR-009` | `TC-002`, `TC-007`, `TC-011`, `TC-012`, `TC-013`, `TC-015` | Scope pulse width traces & video of mechanical eyelids | None |
| `US-006` (Power Isolation) | `FR-012`, `NFR-003` | `TC-012` | Schematic review, ADC calibration log, voltmeter check | None |
| `US-007` (Hopping Leg System) | `FR-009`, `FR-011`, `FR-022`, `NFR-004` | `TC-008`, `TC-010` | Video of forward/reverse hopping & double-crank drawing | None |
| `US-008` (Filaments & Bearings) | `NFR-004` | Inspection Check | Physical inspection of PETG/TPU prints & bearing assembly photo | None |
| `US-009` (Spacious Shell & Charger) | `FR-023`, `FR-024`, `NFR-010` | `TC-019`, Inspection | Charging current profile log, cell balance check, shell measurement | None |
| `US-010` (CAD Sourcing Time Limit) | `NFR-011` | Audit Check | Verify STL files exist & project log shows <= 1 week on CAD | None |
| `US-011` (Active Steering Turns) | `FR-025` | `TC-020` | Tail-skid linkage clearance check & video of motion turns | None |
| `US-013` (90-Degree Kick Locomotion) | `FR-026` | `TC-021` | Slow-motion video verifying 5-15 mm ground clearance lift | None |

---

## 5. Risk Matrix

| ID | Category | Tier Affected | Severity | Probability | Impact | Mitigation | Human Approval Required |
|---|---|---|---|---|---|---|---|
| `R-001` | Voltage / Power | Recommended | Low | Low | MCU brownout / reset when central DC motor starts | Separate independent regulators power MCU logic and motor path; decoupling capacitors placed near driver | No |
| `R-002` | Safety | Recommended | Medium | Low | Motor running indefinitely if ultrasonic sensor Echo hangs | Software 250 ms watchdog task (`FR-016`) halts motor, centers steering, droops ears, and closes eyelids | No |
| `R-003` | Mechanical Linkages | Recommended | High | Low | Brittle linkage joints fracturing under hopping ground impact | Leg linkages and structural mounts printed strictly in PETG (`NFR-004`); feet use TPU damping pads | No |
| `R-004` | Electrical | Recommended | Low | Medium | High motor current noise causing UART packet corruption | Implemented software ACK confirmation protocol (`FR-015`) to verify message delivery before next dispatch | No |
| `R-005` | Electrical | Core / Rec | High | Low | Connecting 5V sensor outputs directly to 3.3V MCU inputs damaging silicon | Native 3.3V modules used (RCWL-1601), or 10k/4.7k resistor voltage dividers inserted on feedback signals | No |
| `R-006` | Acoustic / EMI | Core | Low | Low | I2S audio signals creating crosstalk noise on LPUART lines | Physical trace separation: I2S and LPUART wiring routed in opposite directions using isolated copper wires | No |
| `R-007` | Privacy / Security | Core | High | Low | Stored Wi-Fi keys or conversation cache leaked between test users | 10-second button NVS wiping routine (`FR-018`), post-speech RAM zero-filling (`FR-020`), TLS encryption (`NFR-008`) | No |
| `R-008` | Mechanical Control | Recommended | Medium | Medium | Joint binding or phase drift between left and right legs causing tipping | Shared mechanical double-crank axle (`FR-022`) driven by 1x motor; MR85ZZ ball bearings at all pivot pins | No |
| `R-009` | Battery Safety | Recommended | High | Low | 2S LiPo battery overcharge, over-discharge, or thermal runaway | Integrated 2S balance charger (`FR-023`) and 2S BMS protection board (`NFR-010`) enforcing 6.0V cutoff | No |
| `R-010` | Thermal Heat | Recommended | Medium | Low | Component density inside closed shell causing thermal throttling | PLA outer body shell (`FR-024`) designed with multiple passive airflow ventilation grilles | No |
| `R-011` | Mechanical CAD Sourcing | Recommended | Medium | High | Learning CAD tools (e.g. Blender) consuming vital project time | Sourcing pre-designed STL/STEP templates is highly recommended; limit custom CAD design to max 1 week (`NFR-011`) | Yes |
| `R-012` | Steering Jamming | Recommended | Low | Low | Rear tail-skid steering linkage jamming against outer body shell | Linkage design enclosed within shell bounds with mechanical clearance >= 10 mm | No |
| `R-013` | Landing Impact Shock | Recommended | Medium | Low | Peak landing impact forces stripping TT gear motor teeth or cracking mounts | Jointed PETG legs with TPU landing pads absorb impact; 90-degree kick generates a gentle low-lift (5-15 mm) hop | No |

---

## 6. Assumptions and Open Questions

### 6.1 Confirmed Facts

- The project represents a Mechanized Bunny that has conversations with a human.
- The bunny physically follows the user using distance sensors.
- The bunny mimics emotional expressions based on conversation mood using physical ear sweeps and organic eyelid movements.
- The bunny retrieves answers and mood data from a Cloud AI API endpoint.
- The target hardware suite is fixed: **NXP FRDM-MCXA153 board** as the main controller, and an **ESP32 coprocessor suite (ESP32-S3 Nano)** for Wi-Fi connectivity.
- Dual-processor architecture is permitted: MCXA153 manages low-level motor/servo timing and sensors; ESP32-S3 Nano manages Wi-Fi, HTTPS REST API, JSON parsing, and I2S audio rendering.
- Power is supplied by a single 2S LiPo battery pack with separate, independent regulators powering digital logic and motor paths.
- Structural mounts, crank arms, and leg linkages must be printed strictly in **PETG** filament; landing pads use **TPU**; body shell uses **PLA**.
- A software UART acknowledgment (ACK) protocol (`0x06`) is used to confirm command delivery.
- Logic interface matching uses resistor voltage dividers or native 3.3V modules.
- Status LEDs are completely excluded; state feedback (awake, searching, sleeping, low battery) is conveyed organically via physical eyelid servo positions and ear sweeps.
- Locomotion is achieved by a hopping leg linkage driven by **1x central high-torque DC gear motor** rotating a shared double-crank axle to lock leg phase.
- Locomotion utilizes a 90-degree rotary leg kick generating a gentle, low-amplitude hop (5 to 15 mm lift).
- Active steering is achieved via an SG90 micro servo pivoting a rear tail-skid assembly (+/-30 degrees).
- Outer body shell is spacious (~180x120x120 mm) with airflow ventilation grilles and magnetic quick-release latches.
- Battery charging uses an onboard 2S USB-C balance charger module and 2S BMS protection board.
- The total project delivery duration for students is 7 weeks. Sourcing pre-designed 3D model files (STL/STEP) is highly recommended; custom CAD learning/design must be strictly capped at 1 week.

### 6.2 AI Assumptions

- `A-001` (Autonomous Network Flow): The bunny does not require a local smartphone app during normal operation; ESP32 connects directly to Wi-Fi upon boot using NVS keys.
- `A-002` (Cloud API Payload): Cloud API is an HTTP REST service returning a simple JSON object containing `reply` (string), `mood` (string), and `servo_angle` (integer).
- `A-003` (Coprocessor Division of Labor): ESP32-S3 Nano handles networking, SSL/TLS, API parsing, and direct I2S audio rendering; MCXA153 handles PWM motor/servos, ultrasonic timing, and battery ADC.
- `A1-001` (User Distance Thresholds): Target distance for user tracking is set to a 30–50 cm window.
- `A1-002` (Control Loop Period): The DC motor speed update control loop runs periodically every 50 ms.
- `A1-003` (Servo PWM Frequency): PWM control signals for ear, eyelid, and steering servos run at 50 Hz (20 ms period).
- `A1-004` (UART Configuration): LPUART link operates at 115200 baud, 8-N-1 formatting.
- `A1-005` (Battery ADC Scaling): 2S LiPo battery (8.4V max) is scaled down using a 10k / 4.7k resistor divider, delivering <= 2.68V to the ADC.
- `A1-006` (Spacious Shell Envelope): Outer shell dimensions are set to approximately 180 mm (L) x 120 mm (W) x 120 mm (H).
- `A1-007` (3D Asset Sourcing): 3D mechanical models and shell files are sourced from pre-existing course templates or open-source repositories.

### 6.3 Open Questions

| ID | Question | Why It Matters | Owner | Status |
|---|---|---|---|---|
| `Q-001` | What exact HTTP REST API endpoint and authentication header format will be used for the summer school Cloud AI service? | Determines JSON parsing key names and header buffer memory sizing on the ESP32-S3 Nano. | Instructor / Student | Open |
| `Q-002` | Are pre-designed 3D printable STL/STEP files for the double-crank leg linkage and spacious shell available in the course repository? | If templates are unavailable, student must immediately allocate 1 week of the 7-week timeline for custom Blender CAD design. | Instructor | Open |
| `Q-003` | What gear reduction ratio (1:120 vs 1:220) is preferred for the central DC TT gear motor? | Higher gear reduction (1:220) provides superior torque for lifting the chassis during the 90-degree kick phase but reduces hopping speed. | Student | Open |
| `Q-004` | What specific model of 2S USB-C balance charger module (IP2326 vs TP5100) will be supplied in the lab kit? | Affects PCB footprint mounting and USB-C panel wiring layout inside the shell. | Instructor / Student | Open |

---

## 7. Human Review Checklist

- [ ] Scope approved
- [ ] Selected feature tier approved (Recommended Summer School Version)
- [ ] FRDM-MCXA153 confirmed as mandatory target board for low-level control
- [ ] FRDM-MCXA153 pinout and LPUART / PWM peripheral assignments checked
- [ ] Voltage compatibility checked (3.3V logic boundaries enforced; zero 5V directly to MCU)
- [ ] Current limits checked (motor and servos powered from dedicated 5V/6V regulator rail)
- [ ] Power budget checked (2S LiPo battery, 2S BMS cutoff at 6.0V, 10k/4.7k ADC divider)
- [ ] External modules checked (RCWL-1601 ultrasonic, MAX98357A DAC, TB6612FNG driver)
- [ ] Advanced components approved or removed (Voice mic & camera reserved for Advanced tier)
- [ ] Sensor/actuator interfaces confirmed (Ultrasonic capture, 4x PWM servos, H-bridge DC motor)
- [ ] Firmware architecture approved (Dual-processor asynchronous superloop with UART ACK check)
- [ ] Timing and memory constraints reviewed (50 ms loop period, SRAM usage <= 28 KB)
- [ ] Test plan reviewed (TC-001 through TC-021 linked to Must requirements)
- [ ] Traceability reviewed (All user stories mapped to system requirements and test cases)
- [ ] Safety/privacy/security risks reviewed (TLS encryption, 10s button NVS wipe, RAM zero-fill)
- [ ] AI assumptions accepted or rejected (30-50 cm window, 6.4V low battery cutoff, 50 ms loop)
- [ ] Implementation allowed to start

---

## 8. Obtained Results

```markdown
TODO: Complete after implementation.

Describe:
- what was implemented;
- what works;
- what does not work yet;
- measurements and test results;
- photos or screenshots;
- demo observations;
- limitations.
```

---

## 9. Conclusions

```markdown
TODO: Complete at the end of the project.

Discuss:
- what was learned;
- what worked well;
- what was difficult;
- what would be improved in a future version;
- how Gen AI helped or failed to help.
```

---

## 10. Download

```markdown
TODO: Add links or attach:
- source code archive;
- schematic files;
- build instructions;
- README;
- ChangeLog;
- test logs;
- demo video;
- final presentation.
```

---

## 11. Project Journal

| Date | Work Completed | Problems / Risks | Next Steps | Author |
|---|---|---|---|---|
| `TODO` | `TODO` | `TODO` | `TODO` | `TODO` |
| `TODO` | `TODO` | `TODO` | `TODO` | `TODO` |
| `TODO` | `TODO` | `TODO` | `TODO` | `TODO` |
| `TODO` | `TODO` | `TODO` | `TODO` | `TODO` |

---

## 12. Bibliography / Resources

### Hardware Resources

- TODO: FRDM-MCXA153 board documentation and schematic (`FRDM-MCXA153-Board-User-Manual.pdf`).
- TODO: MCXA153 datasheet and reference manual (`MCXA153-Reference-Manual.pdf`).
- TODO: RCWL-1601 / HC-SR04P 3.3V Ultrasonic Distance Sensor datasheet.
- TODO: TB6612FNG Dual H-Bridge Motor Driver datasheet.
- TODO: MAX98357A I2S 3.2W Class D Mono Amplifier datasheet.
- TODO: SG90 Micro Servo datasheet and PWM timing specifications.
- TODO: 2S LiPo battery safety guidelines, 2S BMS specs, and IP2326 / TP5100 balance charger datasheets.

### Software Resources

- TODO: NXP MCUXpresso SDK for MCXA153 documentation and API reference.
- TODO: MCUXpresso Config Tools (Pin Mux, Clock Tool, Peripheral Config).
- TODO: ESP32-S3 Arduino Core / ESP-IDF mbedTLS & HTTP Client documentation.
- TODO: Project GitHub repository and code release archives.

### Learning Resources

- TODO: Course/lab notes for Embedded Engineering and Gen AI Summer School.
- TODO: Proportional control loop tutorials for autonomous mobile tracking.
- TODO: Mechanical 3D printing guidelines for PETG, TPU, and PLA materials.

---

## 13. Documentation Status

`READY FOR HUMAN REVIEW`

- The project documentation draft cleanly integrates all Agent 0 scoping intent and Agent 1 engineering requirements into a structured, DokuWiki-aligned Markdown template.
- Mandatory hardware platform constraints (NXP FRDM-MCXA153 MCU board) and secondary coprocessor assignments (ESP32-S3 Nano) are strictly preserved and validated.
- All functional requirements, non-functional requirements, test plan cases, traceability matrix entries, and risk register items are completely detailed without missing tables.
- Organic status feedback (servo eyelids and ear sweeps without status LEDs), hopping double-crank locomotion with 90-degree rotary kicks, active rear steering tail-skid, onboard USB-C 2S balance charging, and privacy data-wiping mechanisms are fully incorporated.
- Clear `TODO` placeholders and a Human Review Checklist are provided for student implementation and instructor sign-off.

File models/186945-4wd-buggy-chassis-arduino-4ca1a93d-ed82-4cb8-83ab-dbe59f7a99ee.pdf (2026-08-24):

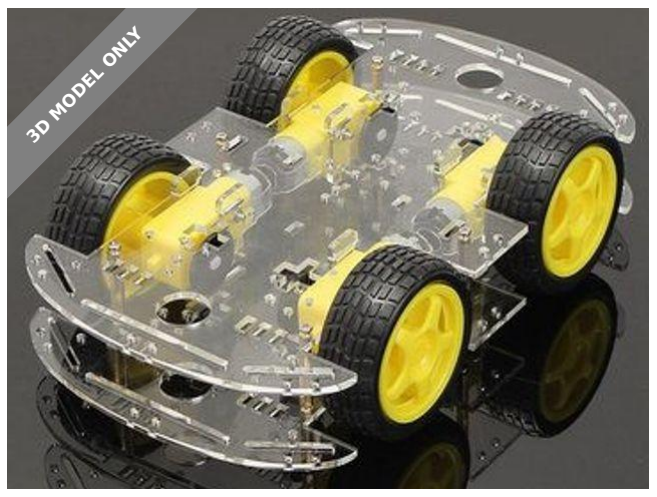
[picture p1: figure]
3D MODEL ONLY

# Summary

If you like my stuff please consider buying me a coffee https://ko-fi.com/

philm 3D printable replacement chassis plate...

Toys & Games (https://www.printables.com/model?categoryId=30) | > | Other Toys & Games (https://www.printables.com/model?categoryId=47)
Tags: | chassis | robotchassis | 4wdbuggy | vehiclechassiskit

If you like my stuff please consider buying me a coffee https://ko-fi.com/

## philm (https://ko-fi.com/philm)

3D printable replacement chassis plate for the popular 4WD Arduino robot/

smart car

Includes a split version for printing on standard 200 X 200mm beds

To join, lightly sand the joint surfaces then apply super glue.

13-Oct-2020 Added motor mount plate in STP & STL format

Category: Mechanical Toys

P (https://www.printables.com/social/261514/about) Phil M (https://www.printables.com/social/261514/about)

# 4WD buggy chassis Arduino

### VIEW IN BROWSER (https://www.printables.com/model/186945-4wd-buggy-chassis-arduino)

updated 1. 5. 2022 | published 1. 5. 2022

# Model files

Find source .stl files on Thingiverse.com (https://www.thingiverse.com/thing:2945466)

## buggy_chassis_orig_v4.dxf

## 4wd_smart_buggy_chassis_1piece.stl

## buggy_chassis_w_servo_v4.dxf

## 4wd_smart_buggy_chassis_part_a.stl

## motor_mount.step

## buggy_chassis_w_servo_rot_90_deg.dxf

## 4wd_smart_buggy_chassis_part_b.stl

## motor_mount.stl

## 4wd_arduino_buggy_motor_mount_v1.dxf

# License

This work is licensed under a

Creative Commons (4.0 International License)

Attribution—Noncommercial—Share Alike (http://creativecommons.org/licenses/by-nc-sa/4.0/)

### ✖ | Sharing without ATTRIBUTION

✔ | Remix Culture allowed
✖ | Commercial Use
✖ | Free Cultural Works
✖ | Meets Open Definition

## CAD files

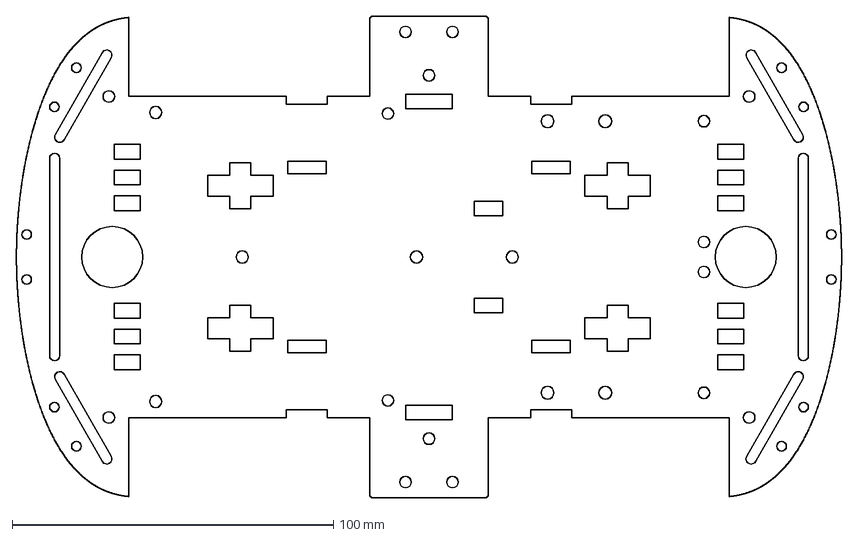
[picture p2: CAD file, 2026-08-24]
models/buggy_chassis_orig_v4.dxf
257.0 x 150.0 mm

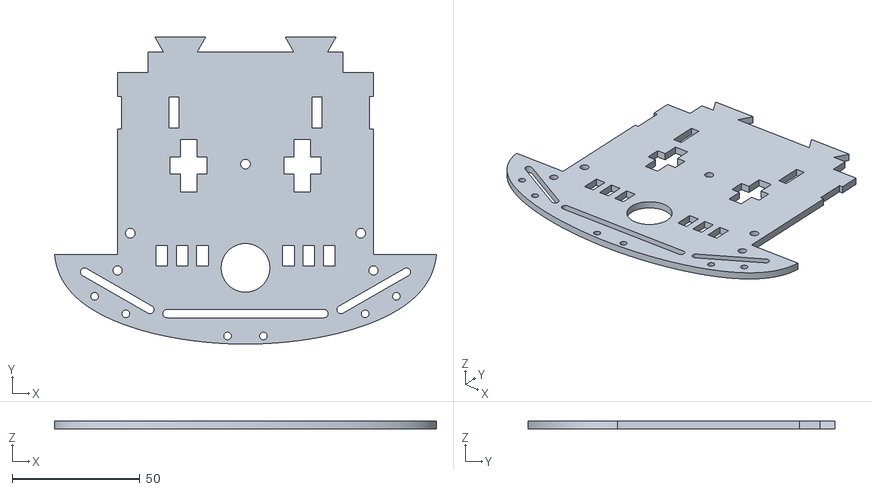
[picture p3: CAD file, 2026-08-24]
models/4wd_smart_buggy_chassis_part_a.stl
149.2 x 120.0 x 3.00

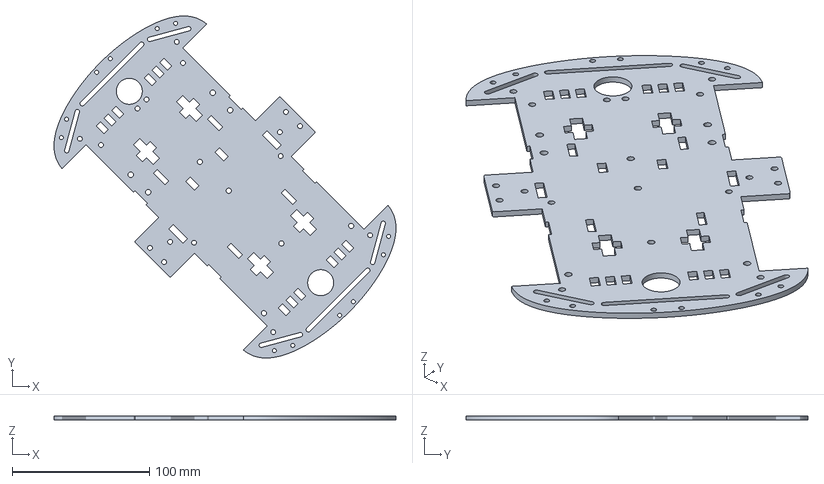
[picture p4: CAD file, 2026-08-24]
models/4wd_smart_buggy_chassis_1piece.3mf
249.4 x 249.4 x 3.00 mm

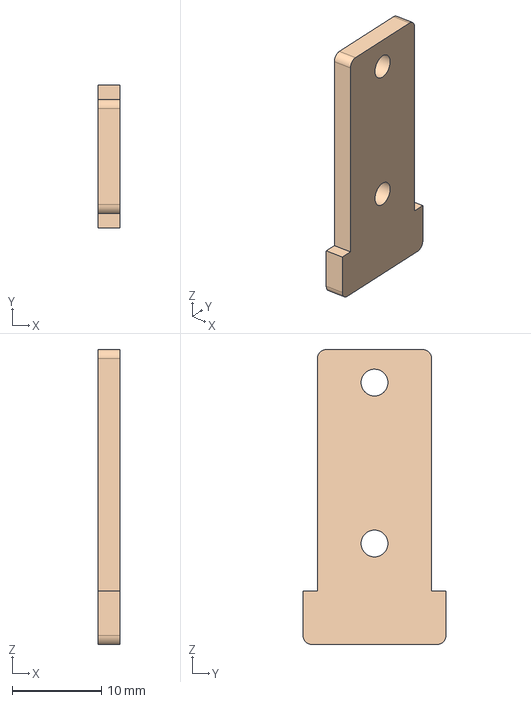
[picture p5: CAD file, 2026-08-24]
models/motor_mount.step
2.50 x 16.0 x 33.0 mm

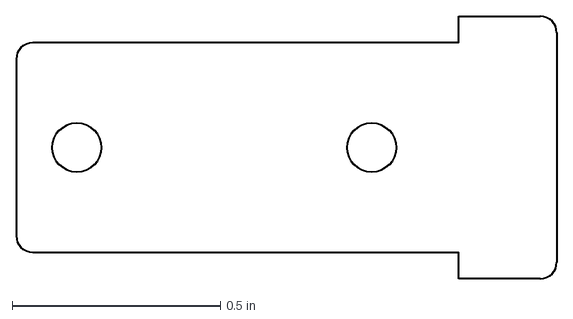
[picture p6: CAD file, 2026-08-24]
models/4wd_arduino_buggy_motor_mount_v1.dxf
1.30 x 0.63 in

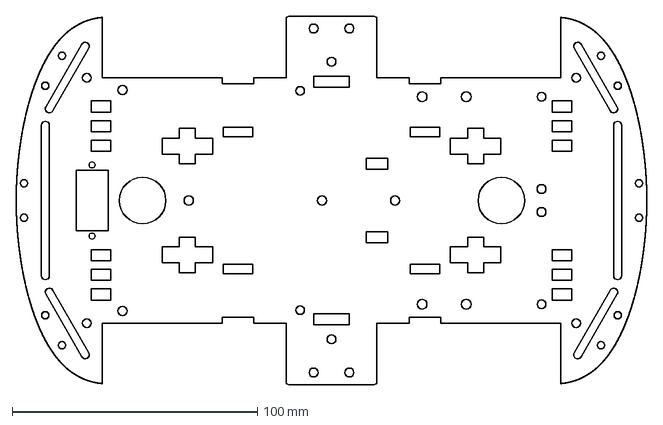
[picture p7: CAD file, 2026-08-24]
models/buggy_chassis_w_servo_v4.dxf
257.0 x 150.0 mm

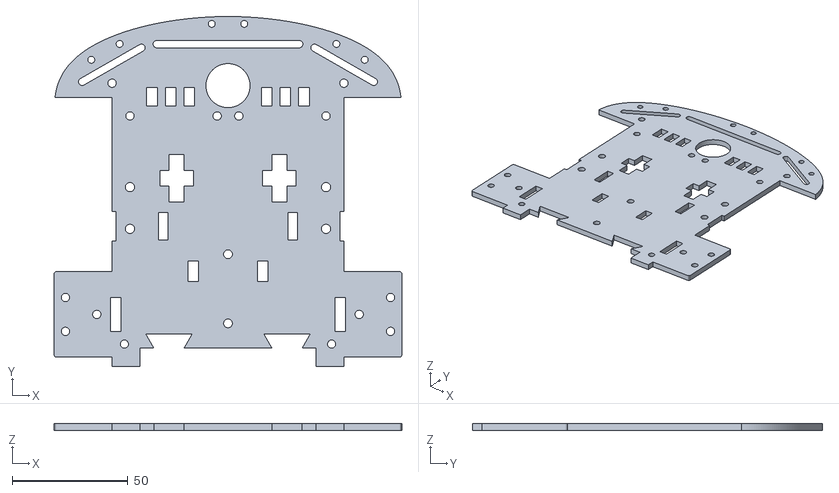
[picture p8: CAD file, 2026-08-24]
models/4wd_smart_buggy_chassis_part_b.stl
150.0 x 151.0 x 3.00

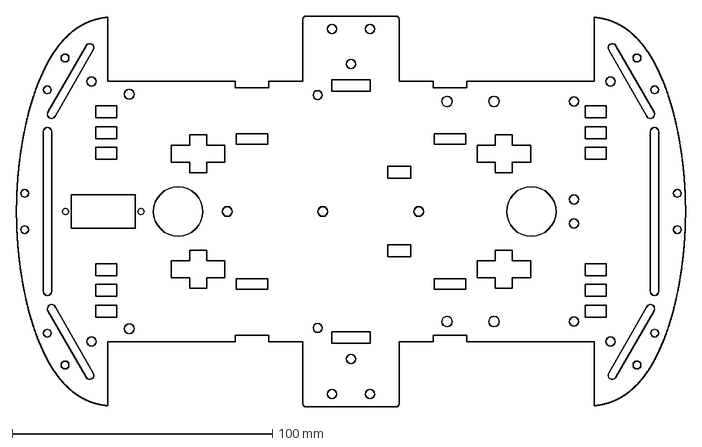
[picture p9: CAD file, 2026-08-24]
models/buggy_chassis_w_servo_rot_90_deg.dxf
257.0 x 150.0 mm

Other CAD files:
models/4wd_smart_buggy_chassis_1piece.stl
models/motor_mount.3mf
models/motor_mount.stl

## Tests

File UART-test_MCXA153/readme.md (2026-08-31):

# hello_world

## Overview
The Hello World demo application provides a sanity check for the new SDK build environments and board bring up. The Hello
World demo prints the "Hello World" string to the terminal using the SDK UART drivers. The purpose of this demo is to
show how to use the UART, and to provide a simple project for debugging and further development.
Note: Please input one character at a time. If you input too many characters each time, the receiver may overflow
because the low level UART uses simple polling way for receiving. If you want to try inputting many characters each time,
just define DEBUG_CONSOLE_TRANSFER_NON_BLOCKING in your project to use the advanced debug console utility (only
debug_console supports this, debug_console_lite doesn't support).

## Supported Boards
- [FRDM-MCXA153](#board-specific-information-for-frdmmcxa153)

---

## Board-Specific Information for frdmmcxa153

### Hardware requirements
- Type-C USB cable
- FRDM-MCXA153 board
- Personal Computer

### Board settings
No special settings are required.

### Prepare the Demo
1.  Connect a Type-C USB cable between the host PC and the MCU-Link port(J15) on the target board.
2.  Open a serial terminal with the following settings:
    - 115200 baud rate
    - 8 data bits
    - No parity
    - One stop bit
    - No flow control
3.  Download the program to the target board.
4.  Either press the reset button on your board or launch the debugger in your IDE to begin running the demo.

### Running the demo
The log below shows the output of the hello world demo in the terminal window:
~~~~~~~~~~~~~~~~~~~~~~~~~~~~~~~~~~~
hello world.
~~~~~~~~~~~~~~~~~~~~~~~~~~~~~~~~~~~

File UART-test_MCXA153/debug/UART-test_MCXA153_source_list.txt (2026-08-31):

/home/bnuy/Desktop/Mecha-Iepurele/UART-test_MCXA153/debug/mcux_config.h;/home/bnuy/Desktop/Mecha-Iepurele/UART-test_MCXA153/debug/mcuxsdk_version.h;/home/bnuy/Desktop/mcusdk/mcuxsdk/mcuxsdk/devices/MCX/MCXA/MCXA153/fsl_device_registers.h;/home/bnuy/Desktop/mcusdk/mcuxsdk/mcuxsdk/devices/MCX/MCXA/MCXA153/MCXA153.h;/home/bnuy/Desktop/mcusdk/mcuxsdk/mcuxsdk/devices/MCX/MCXA/MCXA153/MCXA153_features.h;/home/bnuy/Desktop/mcusdk/mcuxsdk/mcuxsdk/devices/MCX/MCXA/MCXA153/MCXA153_COMMON.h;/home/bnuy/Desktop/mcusdk/mcuxsdk/mcuxsdk/devices/MCX/MCXA/periph/PERI_ADC.h;/home/bnuy/Desktop/mcusdk/mcuxsdk/mcuxsdk/devices/MCX/MCXA/periph/PERI_AOI.h;/home/bnuy/Desktop/mcusdk/mcuxsdk/mcuxsdk/devices/MCX/MCXA/periph/PERI_CDOG.h;/home/bnuy/Desktop/mcusdk/mcuxsdk/mcuxsdk/devices/MCX/MCXA/periph/PERI_CMC.h;/home/bnuy/Desktop/mcusdk/mcuxsdk/mcuxsdk/devices/MCX/MCXA/periph/PERI_CRC.h;/home/bnuy/Desktop/mcusdk/mcuxsdk/mcuxsdk/devices/MCX/MCXA/periph/PERI_CTIMER.h;/home/bnuy/Desktop/mcusdk/mcuxsdk/mcuxsdk/devices/MCX/MCXA/periph/PERI_DEBUGMAILBOX.h;/home/bnuy/Desktop/mcusdk/mcuxsdk/mcuxsdk/devices/MCX/MCXA/periph/PERI_DMA.h;/home/bnuy/Desktop/mcusdk/mcuxsdk/mcuxsdk/devices/MCX/MCXA/periph/PERI_EIM.h;/home/bnuy/Desktop/mcusdk/mcuxsdk/mcuxsdk/devices/MCX/MCXA/periph/PERI_EQDC.h;/home/bnuy/Desktop/mcusdk/mcuxsdk/mcuxsdk/devices/MCX/MCXA/periph/PERI_ERM.h;/home/bnuy/Desktop/mcusdk/mcuxsdk/mcuxsdk/devices/MCX/MCXA/periph/PERI_FMC.h;/home/bnuy/Desktop/mcusdk/mcuxsdk/mcuxsdk/devices/MCX/MCXA/periph/PERI_FMU.h;/home/bnuy/Desktop/mcusdk/mcuxsdk/mcuxsdk/devices/MCX/MCXA/periph/PERI_FMUTEST.h;/home/bnuy/Desktop/mcusdk/mcuxsdk/mcuxsdk/devices/MCX/MCXA/periph/PERI_FREQME.h;/home/bnuy/Desktop/mcusdk/mcuxsdk/mcuxsdk/devices/MCX/MCXA/periph/PERI_GLIKEY.h;/home/bnuy/Desktop/mcusdk/mcuxsdk/mcuxsdk/devices/MCX/MCXA/periph/PERI_GPIO.h;/home/bnuy/Desktop/mcusdk/mcuxsdk/mcuxsdk/devices/MCX/MCXA/periph/PERI_I3C.h;/home/bnuy/Desktop/mcusdk/mcuxsdk/mcuxsdk/devices/MCX/MCXA/periph/PERI_INPUTMUX.h;/home/bnuy/Desktop/mcusdk/mcuxsdk/mcuxsdk/devices/MCX/MCXA/periph/PERI_LPCMP.h;/home/bnuy/Desktop/mcusdk/mcuxsdk/mcuxsdk/devices/MCX/MCXA/periph/PERI_LPI2C.h;/home/bnuy/Desktop/mcusdk/mcuxsdk/mcuxsdk/devices/MCX/MCXA/periph/PERI_LPSPI.h;/home/bnuy/Desktop/mcusdk/mcuxsdk/mcuxsdk/devices/MCX/MCXA/periph/PERI_LPTMR.h;/home/bnuy/Desktop/mcusdk/mcuxsdk/mcuxsdk/devices/MCX/MCXA/periph/PERI_LPUART.h;/home/bnuy/Desktop/mcusdk/mcuxsdk/mcuxsdk/devices/MCX/MCXA/periph/PERI_MRCC.h;/home/bnuy/Desktop/mcusdk/mcuxsdk/mcuxsdk/devices/MCX/MCXA/periph/PERI_OSTIMER.h;/home/bnuy/Desktop/mcusdk/mcuxsdk/mcuxsdk/devices/MCX/MCXA/periph/PERI_PORT.h;/home/bnuy/Desktop/mcusdk/mcuxsdk/mcuxsdk/devices/MCX/MCXA/periph/PERI_PWM.h;/home/bnuy/Desktop/mcusdk/mcuxsdk/mcuxsdk/devices/MCX/MCXA/periph/PERI_SCG.h;/home/bnuy/Desktop/mcusdk/mcuxsdk/mcuxsdk/devices/MCX/MCXA/periph/PERI_SPC.h;/home/bnuy/Desktop/mcusdk/mcuxsdk/mcuxsdk/devices/MCX/MCXA/periph/PERI_SYSCON.h;/home/bnuy/Desktop/mcusdk/mcuxsdk/mcuxsdk/devices/MCX/MCXA/periph/PERI_TRDC.h;/home/bnuy/Desktop/mcusdk/mcuxsdk/mcuxsdk/devices/MCX/MCXA/periph/PERI_USB.h;/home/bnuy/Desktop/mcusdk/mcuxsdk/mcuxsdk/devices/MCX/MCXA/periph/PERI_UTICK.h;/home/bnuy/Desktop/mcusdk/mcuxsdk/mcuxsdk/devices/MCX/MCXA/periph/PERI_VBAT.h;/home/bnuy/Desktop/mcusdk/mcuxsdk/mcuxsdk/devices/MCX/MCXA/periph/PERI_WAKETIMER.h;/home/bnuy/Desktop/mcusdk/mcuxsdk/mcuxsdk/devices/MCX/MCXA/periph/PERI_WUU.h;/home/bnuy/Desktop/mcusdk/mcuxsdk/mcuxsdk/devices/MCX/MCXA/periph/PERI_WWDT.h;/home/bnuy/Desktop/mcusdk/mcuxsdk/mcuxsdk/devices/MCX/MCXA/MCXA153/system_MCXA153.c;/home/bnuy/Desktop/mcusdk/mcuxsdk/mcuxsdk/devices/MCX/MCXA/MCXA153/system_MCXA153.h;/home/bnuy/Desktop/mcusdk/mcuxsdk/mcuxsdk/devices/MCX/MCXA/MCXA153/gcc/startup_MCXA153.S;/home/bnuy/Desktop/mcusdk/mcuxsdk/mcuxsdk/devices/MCX/MCXA/MCXA153/drivers/fsl_clock.c;/home/bnuy/Desktop/mcusdk/mcuxsdk/mcuxsdk/devices/MCX/MCXA/MCXA153/drivers/fsl_clock.h;/home/bnuy/Desktop/mcusdk/mcuxsdk/mcuxsdk/devices/MCX/MCXA/MCXA153/drivers/fsl_inputmux_connections.h;/home/bnuy/Desktop/mcusdk/mcuxsdk/mcuxsdk/devices/MCX/MCXA/MCXA153/drivers/fsl_reset.c;/home/bnuy/Desktop/mcusdk/mcuxsdk/mcuxsdk/devices/MCX/MCXA/MCXA153/drivers/fsl_reset.h;/home/bnuy/Desktop/mcusdk/mcuxsdk/mcuxsdk/arch/arm/CMSIS/Core/Include/cmsis_compiler.h;/home/bnuy/Desktop/mcusdk/mcuxsdk/mcuxsdk/arch/arm/CMSIS/Core/Include/cmsis_version.h;/home/bnuy/Desktop/mcusdk/mcuxsdk/mcuxsdk/arch/arm/CMSIS/Core/Include/cmsis_gcc.h;/home/bnuy/Desktop/mcusdk/mcuxsdk/mcuxsdk/arch/arm/CMSIS/Core/Include/m-profile/cmsis_gcc_m.h;/home/bnuy/Desktop/mcusdk/mcuxsdk/mcuxsdk/arch/arm/CMSIS/Core/Include/core_cm33.h;/home/bnuy/Desktop/mcusdk/mcuxsdk/mcuxsdk/arch/arm/CMSIS/Core/Include/m-profile/armv8m_mpu.h;/home/bnuy/Desktop/mcusdk/mcuxsdk/mcuxsdk/arch/arm/CMSIS/Core/Include/tz_context.h;/home/bnuy/Desktop/mcusdk/mcuxsdk/mcuxsdk/drivers/common/fsl_common.h;/home/bnuy/Desktop/mcusdk/mcuxsdk/mcuxsdk/drivers/common/fsl_common.c;/home/bnuy/Desktop/mcusdk/mcuxsdk/mcuxsdk/drivers/common/fsl_common_arm.c;/home/bnuy/Desktop/mcusdk/mcuxsdk/mcuxsdk/drivers/common/fsl_common_arm.h;/home/bnuy/Desktop/mcusdk/mcuxsdk/mcuxsdk/drivers/gpio/fsl_gpio.h;/home/bnuy/Desktop/mcusdk/mcuxsdk/mcuxsdk/drivers/gpio/fsl_gpio.c;/home/bnuy/Desktop/mcusdk/mcuxsdk/mcuxsdk/drivers/lpuart/fsl_lpuart.h;/home/bnuy/Desktop/mcusdk/mcuxsdk/mcuxsdk/drivers/lpuart/fsl_lpuart.c;/home/bnuy/Desktop/mcusdk/mcuxsdk/mcuxsdk/drivers/mcx_spc/fsl_spc.h;/home/bnuy/Desktop/mcusdk/mcuxsdk/mcuxsdk/drivers/mcx_spc/fsl_spc.c;/home/bnuy/Desktop/mcusdk/mcuxsdk/mcuxsdk/drivers/port/fsl_port.h;/home/bnuy/Desktop/mcusdk/mcuxsdk/mcuxsdk/components/assert/fsl_assert.h;/home/bnuy/Desktop/mcusdk/mcuxsdk/mcuxsdk/components/assert/fsl_assert.c;/home/bnuy/Desktop/mcusdk/mcuxsdk/mcuxsdk/components/debug_console_lite/fsl_debug_console.h;/home/bnuy/Desktop/mcusdk/mcuxsdk/mcuxsdk/components/debug_console_lite/fsl_debug_console.c;/home/bnuy/Desktop/mcusdk/mcuxsdk/mcuxsdk/components/misc_utilities/fsl_syscall_stub.c;/home/bnuy/Desktop/mcusdk/mcuxsdk/mcuxsdk/components/misc_utilities/fsl_sbrk.c;/home/bnuy/Desktop/mcusdk/mcuxsdk/mcuxsdk/components/misc_utilities/fsl_memcpy.S;/home/bnuy/Desktop/mcusdk/mcuxsdk/mcuxsdk/components/misc_utilities/fsl_memset.S;/home/bnuy/Desktop/mcusdk/mcuxsdk/mcuxsdk/components/str/fsl_str.h;/home/bnuy/Desktop/mcusdk/mcuxsdk/mcuxsdk/components/str/fsl_str.c;/home/bnuy/Desktop/mcusdk/mcuxsdk/mcuxsdk/components/uart/fsl_adapter_uart.h;/home/bnuy/Desktop/mcusdk/mcuxsdk/mcuxsdk/components/uart/fsl_adapter_lpuart.c;/home/bnuy/Desktop/Mecha-Iepurele/UART-test_MCXA153/frdmmcxa153/frdmmcxa153/board.c;/home/bnuy/Desktop/Mecha-Iepurele/UART-test_MCXA153/frdmmcxa153/frdmmcxa153/board.h;/home/bnuy/Desktop/Mecha-Iepurele/UART-test_MCXA153/frdmmcxa153/frdmmcxa153/clock_config.c;/home/bnuy/Desktop/Mecha-Iepurele/UART-test_MCXA153/frdmmcxa153/frdmmcxa153/clock_config.h;/home/bnuy/Desktop/Mecha-Iepurele/UART-test_MCXA153/frdmmcxa153/hello_world/pin_mux.c;/home/bnuy/Desktop/Mecha-Iepurele/UART-test_MCXA153/frdmmcxa153/hello_world/pin_mux.h;/home/bnuy/Desktop/Mecha-Iepurele/UART-test_MCXA153/frdmmcxa153/hello_world/app.h;/home/bnuy/Desktop/Mecha-Iepurele/UART-test_MCXA153/frdmmcxa153/hello_world/hardware_init.c;/home/bnuy/Desktop/Mecha-Iepurele/UART-test_MCXA153/hello_world.c;/home/bnuy/Desktop/mcusdk/mcuxsdk/mcuxsdk/devices/MCX/MCXA/MCXA153/gcc/MCXA153_flash.ld

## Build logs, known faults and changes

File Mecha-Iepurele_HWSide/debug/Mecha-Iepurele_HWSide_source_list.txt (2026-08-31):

/home/bnuy/Desktop/Mecha-Iepurele/Mecha-Iepurele_HWSide/debug/mcux_config.h;/home/bnuy/Desktop/Mecha-Iepurele/Mecha-Iepurele_HWSide/debug/mcuxsdk_version.h;/home/bnuy/Desktop/mcusdk/mcuxsdk/mcuxsdk/devices/MCX/MCXA/MCXA153/fsl_device_registers.h;/home/bnuy/Desktop/mcusdk/mcuxsdk/mcuxsdk/devices/MCX/MCXA/MCXA153/MCXA153.h;/home/bnuy/Desktop/mcusdk/mcuxsdk/mcuxsdk/devices/MCX/MCXA/MCXA153/MCXA153_features.h;/home/bnuy/Desktop/mcusdk/mcuxsdk/mcuxsdk/devices/MCX/MCXA/MCXA153/MCXA153_COMMON.h;/home/bnuy/Desktop/mcusdk/mcuxsdk/mcuxsdk/devices/MCX/MCXA/periph/PERI_ADC.h;/home/bnuy/Desktop/mcusdk/mcuxsdk/mcuxsdk/devices/MCX/MCXA/periph/PERI_AOI.h;/home/bnuy/Desktop/mcusdk/mcuxsdk/mcuxsdk/devices/MCX/MCXA/periph/PERI_CDOG.h;/home/bnuy/Desktop/mcusdk/mcuxsdk/mcuxsdk/devices/MCX/MCXA/periph/PERI_CMC.h;/home/bnuy/Desktop/mcusdk/mcuxsdk/mcuxsdk/devices/MCX/MCXA/periph/PERI_CRC.h;/home/bnuy/Desktop/mcusdk/mcuxsdk/mcuxsdk/devices/MCX/MCXA/periph/PERI_CTIMER.h;/home/bnuy/Desktop/mcusdk/mcuxsdk/mcuxsdk/devices/MCX/MCXA/periph/PERI_DEBUGMAILBOX.h;/home/bnuy/Desktop/mcusdk/mcuxsdk/mcuxsdk/devices/MCX/MCXA/periph/PERI_DMA.h;/home/bnuy/Desktop/mcusdk/mcuxsdk/mcuxsdk/devices/MCX/MCXA/periph/PERI_EIM.h;/home/bnuy/Desktop/mcusdk/mcuxsdk/mcuxsdk/devices/MCX/MCXA/periph/PERI_EQDC.h;/home/bnuy/Desktop/mcusdk/mcuxsdk/mcuxsdk/devices/MCX/MCXA/periph/PERI_ERM.h;/home/bnuy/Desktop/mcusdk/mcuxsdk/mcuxsdk/devices/MCX/MCXA/periph/PERI_FMC.h;/home/bnuy/Desktop/mcusdk/mcuxsdk/mcuxsdk/devices/MCX/MCXA/periph/PERI_FMU.h;/home/bnuy/Desktop/mcusdk/mcuxsdk/mcuxsdk/devices/MCX/MCXA/periph/PERI_FMUTEST.h;/home/bnuy/Desktop/mcusdk/mcuxsdk/mcuxsdk/devices/MCX/MCXA/periph/PERI_FREQME.h;/home/bnuy/Desktop/mcusdk/mcuxsdk/mcuxsdk/devices/MCX/MCXA/periph/PERI_GLIKEY.h;/home/bnuy/Desktop/mcusdk/mcuxsdk/mcuxsdk/devices/MCX/MCXA/periph/PERI_GPIO.h;/home/bnuy/Desktop/mcusdk/mcuxsdk/mcuxsdk/devices/MCX/MCXA/periph/PERI_I3C.h;/home/bnuy/Desktop/mcusdk/mcuxsdk/mcuxsdk/devices/MCX/MCXA/periph/PERI_INPUTMUX.h;/home/bnuy/Desktop/mcusdk/mcuxsdk/mcuxsdk/devices/MCX/MCXA/periph/PERI_LPCMP.h;/home/bnuy/Desktop/mcusdk/mcuxsdk/mcuxsdk/devices/MCX/MCXA/periph/PERI_LPI2C.h;/home/bnuy/Desktop/mcusdk/mcuxsdk/mcuxsdk/devices/MCX/MCXA/periph/PERI_LPSPI.h;/home/bnuy/Desktop/mcusdk/mcuxsdk/mcuxsdk/devices/MCX/MCXA/periph/PERI_LPTMR.h;/home/bnuy/Desktop/mcusdk/mcuxsdk/mcuxsdk/devices/MCX/MCXA/periph/PERI_LPUART.h;/home/bnuy/Desktop/mcusdk/mcuxsdk/mcuxsdk/devices/MCX/MCXA/periph/PERI_MRCC.h;/home/bnuy/Desktop/mcusdk/mcuxsdk/mcuxsdk/devices/MCX/MCXA/periph/PERI_OSTIMER.h;/home/bnuy/Desktop/mcusdk/mcuxsdk/mcuxsdk/devices/MCX/MCXA/periph/PERI_PORT.h;/home/bnuy/Desktop/mcusdk/mcuxsdk/mcuxsdk/devices/MCX/MCXA/periph/PERI_PWM.h;/home/bnuy/Desktop/mcusdk/mcuxsdk/mcuxsdk/devices/MCX/MCXA/periph/PERI_SCG.h;/home/bnuy/Desktop/mcusdk/mcuxsdk/mcuxsdk/devices/MCX/MCXA/periph/PERI_SPC.h;/home/bnuy/Desktop/mcusdk/mcuxsdk/mcuxsdk/devices/MCX/MCXA/periph/PERI_SYSCON.h;/home/bnuy/Desktop/mcusdk/mcuxsdk/mcuxsdk/devices/MCX/MCXA/periph/PERI_TRDC.h;/home/bnuy/Desktop/mcusdk/mcuxsdk/mcuxsdk/devices/MCX/MCXA/periph/PERI_USB.h;/home/bnuy/Desktop/mcusdk/mcuxsdk/mcuxsdk/devices/MCX/MCXA/periph/PERI_UTICK.h;/home/bnuy/Desktop/mcusdk/mcuxsdk/mcuxsdk/devices/MCX/MCXA/periph/PERI_VBAT.h;/home/bnuy/Desktop/mcusdk/mcuxsdk/mcuxsdk/devices/MCX/MCXA/periph/PERI_WAKETIMER.h;/home/bnuy/Desktop/mcusdk/mcuxsdk/mcuxsdk/devices/MCX/MCXA/periph/PERI_WUU.h;/home/bnuy/Desktop/mcusdk/mcuxsdk/mcuxsdk/devices/MCX/MCXA/periph/PERI_WWDT.h;/home/bnuy/Desktop/mcusdk/mcuxsdk/mcuxsdk/devices/MCX/MCXA/MCXA153/system_MCXA153.c;/home/bnuy/Desktop/mcusdk/mcuxsdk/mcuxsdk/devices/MCX/MCXA/MCXA153/system_MCXA153.h;/home/bnuy/Desktop/mcusdk/mcuxsdk/mcuxsdk/devices/MCX/MCXA/MCXA153/gcc/startup_MCXA153.S;/home/bnuy/Desktop/mcusdk/mcuxsdk/mcuxsdk/devices/MCX/MCXA/MCXA153/drivers/fsl_clock.c;/home/bnuy/Desktop/mcusdk/mcuxsdk/mcuxsdk/devices/MCX/MCXA/MCXA153/drivers/fsl_clock.h;/home/bnuy/Desktop/mcusdk/mcuxsdk/mcuxsdk/devices/MCX/MCXA/MCXA153/drivers/fsl_inputmux_connections.h;/home/bnuy/Desktop/mcusdk/mcuxsdk/mcuxsdk/devices/MCX/MCXA/MCXA153/drivers/fsl_reset.c;/home/bnuy/Desktop/mcusdk/mcuxsdk/mcuxsdk/devices/MCX/MCXA/MCXA153/drivers/fsl_reset.h;/home/bnuy/Desktop/mcusdk/mcuxsdk/mcuxsdk/arch/arm/CMSIS/Core/Include/cmsis_compiler.h;/home/bnuy/Desktop/mcusdk/mcuxsdk/mcuxsdk/arch/arm/CMSIS/Core/Include/cmsis_version.h;/home/bnuy/Desktop/mcusdk/mcuxsdk/mcuxsdk/arch/arm/CMSIS/Core/Include/cmsis_gcc.h;/home/bnuy/Desktop/mcusdk/mcuxsdk/mcuxsdk/arch/arm/CMSIS/Core/Include/m-profile/cmsis_gcc_m.h;/home/bnuy/Desktop/mcusdk/mcuxsdk/mcuxsdk/arch/arm/CMSIS/Core/Include/core_cm33.h;/home/bnuy/Desktop/mcusdk/mcuxsdk/mcuxsdk/arch/arm/CMSIS/Core/Include/m-profile/armv8m_mpu.h;/home/bnuy/Desktop/mcusdk/mcuxsdk/mcuxsdk/arch/arm/CMSIS/Core/Include/tz_context.h;/home/bnuy/Desktop/mcusdk/mcuxsdk/mcuxsdk/drivers/common/fsl_common.h;/home/bnuy/Desktop/mcusdk/mcuxsdk/mcuxsdk/drivers/common/fsl_common.c;/home/bnuy/Desktop/mcusdk/mcuxsdk/mcuxsdk/drivers/common/fsl_common_arm.c;/home/bnuy/Desktop/mcusdk/mcuxsdk/mcuxsdk/drivers/common/fsl_common_arm.h;/home/bnuy/Desktop/mcusdk/mcuxsdk/mcuxsdk/drivers/gpio/fsl_gpio.h;/home/bnuy/Desktop/mcusdk/mcuxsdk/mcuxsdk/drivers/gpio/fsl_gpio.c;/home/bnuy/Desktop/mcusdk/mcuxsdk/mcuxsdk/drivers/lpuart/fsl_lpuart.h;/home/bnuy/Desktop/mcusdk/mcuxsdk/mcuxsdk/drivers/lpuart/fsl_lpuart.c;/home/bnuy/Desktop/mcusdk/mcuxsdk/mcuxsdk/drivers/mcx_spc/fsl_spc.h;/home/bnuy/Desktop/mcusdk/mcuxsdk/mcuxsdk/drivers/mcx_spc/fsl_spc.c;/home/bnuy/Desktop/mcusdk/mcuxsdk/mcuxsdk/drivers/port/fsl_port.h;/home/bnuy/Desktop/mcusdk/mcuxsdk/mcuxsdk/drivers/pwm/fsl_pwm.c;/home/bnuy/Desktop/mcusdk/mcuxsdk/mcuxsdk/drivers/pwm/fsl_pwm.h;/home/bnuy/Desktop/mcusdk/mcuxsdk/mcuxsdk/components/assert/fsl_assert.h;/home/bnuy/Desktop/mcusdk/mcuxsdk/mcuxsdk/components/assert/fsl_assert.c;/home/bnuy/Desktop/mcusdk/mcuxsdk/mcuxsdk/components/debug_console_lite/fsl_debug_console.h;/home/bnuy/Desktop/mcusdk/mcuxsdk/mcuxsdk/components/debug_console_lite/fsl_debug_console.c;/home/bnuy/Desktop/mcusdk/mcuxsdk/mcuxsdk/components/misc_utilities/fsl_syscall_stub.c;/home/bnuy/Desktop/mcusdk/mcuxsdk/mcuxsdk/components/misc_utilities/fsl_sbrk.c;/home/bnuy/Desktop/mcusdk/mcuxsdk/mcuxsdk/components/misc_utilities/fsl_memcpy.S;/home/bnuy/Desktop/mcusdk/mcuxsdk/mcuxsdk/components/misc_utilities/fsl_memset.S;/home/bnuy/Desktop/mcusdk/mcuxsdk/mcuxsdk/components/str/fsl_str.h;/home/bnuy/Desktop/mcusdk/mcuxsdk/mcuxsdk/components/str/fsl_str.c;/home/bnuy/Desktop/mcusdk/mcuxsdk/mcuxsdk/components/uart/fsl_adapter_uart.h;/home/bnuy/Desktop/mcusdk/mcuxsdk/mcuxsdk/components/uart/fsl_adapter_lpuart.c;/home/bnuy/Desktop/Mecha-Iepurele/Mecha-Iepurele_HWSide/frdmmcxa153/frdmmcxa153/board.c;/home/bnuy/Desktop/Mecha-Iepurele/Mecha-Iepurele_HWSide/frdmmcxa153/frdmmcxa153/board.h;/home/bnuy/Desktop/Mecha-Iepurele/Mecha-Iepurele_HWSide/frdmmcxa153/frdmmcxa153/clock_config.c;/home/bnuy/Desktop/Mecha-Iepurele/Mecha-Iepurele_HWSide/frdmmcxa153/frdmmcxa153/clock_config.h;/home/bnuy/Desktop/Mecha-Iepurele/Mecha-Iepurele_HWSide/frdmmcxa153/led_blinky/pin_mux.c;/home/bnuy/Desktop/Mecha-Iepurele/Mecha-Iepurele_HWSide/frdmmcxa153/led_blinky/pin_mux.h;/home/bnuy/Desktop/Mecha-Iepurele/Mecha-Iepurele_HWSide/frdmmcxa153/led_blinky/app.h;/home/bnuy/Desktop/Mecha-Iepurele/Mecha-Iepurele_HWSide/frdmmcxa153/led_blinky/hardware_init.c;/home/bnuy/Desktop/Mecha-Iepurele/Mecha-Iepurele_HWSide/led_blinky.c;/home/bnuy/Desktop/Mecha-Iepurele/Mecha-Iepurele_HWSide/led_blinky/peripherals.c;/home/bnuy/Desktop/Mecha-Iepurele/Mecha-Iepurele_HWSide/led_blinky/peripherals.h;/home/bnuy/Desktop/mcusdk/mcuxsdk/mcuxsdk/devices/MCX/MCXA/MCXA153/gcc/MCXA153_flash.ld

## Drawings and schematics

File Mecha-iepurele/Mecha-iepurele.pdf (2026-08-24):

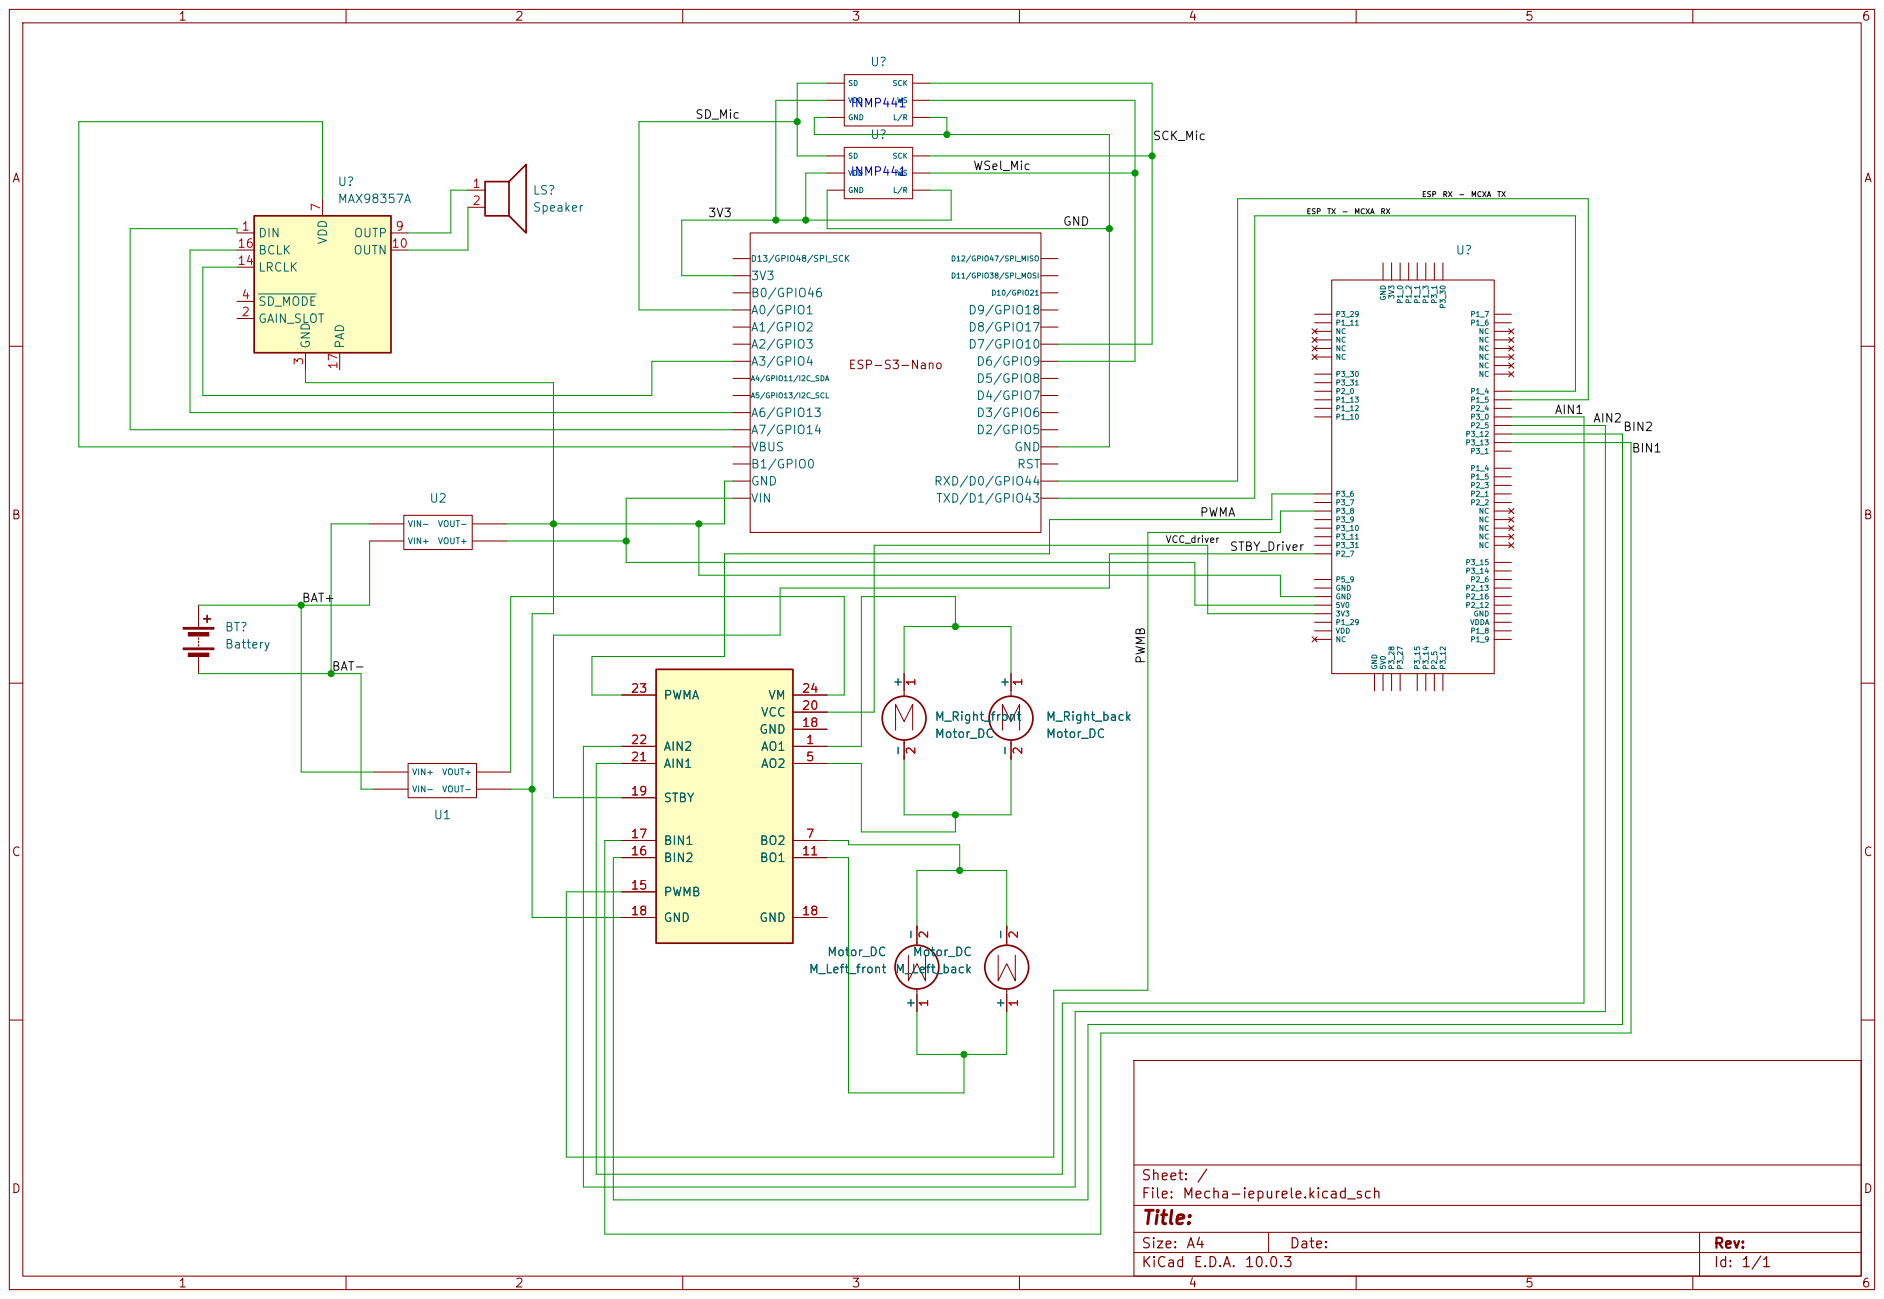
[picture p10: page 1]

ESP TX - MCXA RX

Size: A4 | Rev:
KiCad E.D.A. 10.0.3 | Id: 1/1

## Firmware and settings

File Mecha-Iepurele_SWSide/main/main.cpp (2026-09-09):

#include <stdio.h>
#include <stdlib.h>
#include <string.h>
#include <math.h>
#include "freertos/FreeRTOS.h"
#include "freertos/task.h"
#include "freertos/event_groups.h"
#include "freertos/semphr.h"
#include "driver/uart.h"
#include "driver/gpio.h"
#include "driver/i2s_std.h"
#include "esp_log.h"
#include "esp_task_wdt.h"
#include "esp_wifi.h"
#include "esp_event.h"
#include "nvs_flash.h"
#include "esp_netif.h"
#include "esp_http_server.h"
#include "esp_http_client.h"
#include "esp_crt_bundle.h"
#include "esp_sntp.h"
#include "esp_netif_sntp.h"
#include "esp_heap_caps.h"

static const char *TAG = "ESP32_S3_INMP441_STT";

/* Wi-Fi Router Credentials */
#define WIFI_SSID          ""
#define WIFI_PASS          ""

/* OpenAI API Key Macro */
#define OPENAI_API_KEY     ""

#define UART_PORT_NUM      UART_NUM_1
#define UART_BAUD_RATE     115200
#define UART_TX_PIN        GPIO_NUM_43
#define UART_RX_PIN        GPIO_NUM_44
#define BUF_SIZE           1024

#define I2S_SCK_PIN        GPIO_NUM_4
#define I2S_WS_PIN         GPIO_NUM_5
#define I2S_SD_PIN         GPIO_NUM_21

#define SAMPLE_RATE        16000
#define RECORD_TIME_SEC    30
#define TOTAL_SAMPLES      (SAMPLE_RATE * RECORD_TIME_SEC)
#define TOTAL_PCM_BYTES    (TOTAL_SAMPLES * sizeof(int16_t))
#define CHUNK_SAMPLES      512

#define VAD_SPEECH_THRESHOLD 400
#define AUDIO_GAIN_FACTOR    16

static EventGroupHandle_t s_wifi_event_group;
#define WIFI_CONNECTED_BIT BIT0

/* Buffere globale persistente în PSRAM pentru acces concomitent (Whisper & Web Server) */
static int16_t *g_audio_psram_buf = NULL;
static size_t g_last_recorded_samples = 0;
static SemaphoreHandle_t g_audio_mutex = NULL;

typedef struct __attribute__((packed)) {
    char     riff_header[4];    // "RIFF"
    uint32_t wav_size;          // Total size - 8
    char     wave_header[4];    // "WAVE"
    char     fmt_header[4];     // "fmt "
    uint32_t fmt_chunk_size;    // 16
    uint16_t audio_format;      // 1 (PCM)
    uint16_t num_channels;      // 1 (Mono)
    uint32_t sample_rate;       // 16000
    uint32_t byte_rate;         // sample_rate * 1 * 2 = 32000
    uint16_t block_align;       // 1 * 2 = 2
    uint16_t bits_per_sample;   // 16
    char     data_header[4];    // "data"
    uint32_t data_bytes;        // pcm_bytes
} wav_header_t;

static wav_header_t create_wav_header(uint32_t pcm_bytes, uint32_t sample_rate)
{
    wav_header_t header;
    memcpy(header.riff_header, "RIFF", 4);
    header.wav_size = pcm_bytes + 36;
    memcpy(header.wave_header, "WAVE", 4);
    memcpy(header.fmt_header, "fmt ", 4);
    header.fmt_chunk_size = 16;
    header.audio_format = 1;
    header.num_channels = 1;
    header.sample_rate = sample_rate;
    header.byte_rate = sample_rate * 1 * sizeof(int16_t);
    header.block_align = 1 * sizeof(int16_t);
    header.bits_per_sample = 16;
    memcpy(header.data_header, "data", 4);
    header.data_bytes = pcm_bytes;
    return header;
}

static i2s_chan_handle_t init_inmp441_i2s(void)
{
    i2s_chan_handle_t rx_handle = NULL;
    i2s_chan_config_t chan_cfg = {
        .id = I2S_NUM_0,
        .role = I2S_ROLE_MASTER,
        .dma_desc_num = 24,
        .dma_frame_num = 512,
        .auto_clear = true,
    };
    ESP_ERROR_CHECK(i2s_new_channel(&chan_cfg, NULL, &rx_handle));

    i2s_std_config_t std_cfg = {
        .clk_cfg = I2S_STD_CLK_DEFAULT_CONFIG(SAMPLE_RATE),
        .slot_cfg = I2S_STD_PHILIPS_SLOT_DEFAULT_CONFIG(I2S_DATA_BIT_WIDTH_32BIT, I2S_SLOT_MODE_MONO),
        .gpio_cfg = {
            .mclk = I2S_GPIO_UNUSED,
            .bclk = I2S_SCK_PIN,
            .ws   = I2S_WS_PIN,
            .dout = I2S_GPIO_UNUSED,
            .din  = I2S_SD_PIN,
            .invert_flags = {
                .mclk_inv = false,
                .bclk_inv = false,
                .ws_inv   = false,
            },
        },
    };

    std_cfg.slot_cfg.slot_mask = I2S_STD_SLOT_LEFT;

    ESP_ERROR_CHECK(i2s_channel_init_std_mode(rx_handle, &std_cfg));
    ESP_ERROR_CHECK(i2s_channel_enable(rx_handle));

    ESP_LOGI(TAG, "I2S INMP441 inițializat cu succes.");
    return rx_handle;
}

static bool record_and_evaluate_speech(i2s_chan_handle_t rx_handle)
{
    ESP_LOGI(TAG, "=================================================");
    ESP_LOGI(TAG, " Ascultare Sound Trigger (VAD: %d, Max: %ds)...", VAD_SPEECH_THRESHOLD, RECORD_TIME_SEC);
    ESP_LOGI(TAG, "=================================================");

    int32_t *raw_chunk = (int32_t *)malloc(CHUNK_SAMPLES * sizeof(int32_t));
    if (!raw_chunk || !g_audio_psram_buf) {
        ESP_LOGE(TAG, "Eroare: Lipsă memorie pentru captură!");
        if (raw_chunk) free(raw_chunk);
        return false;
    }

    esp_task_wdt_add(NULL);

    size_t dummy_bytes = 0;
    i2s_channel_read(rx_handle, raw_chunk, CHUNK_SAMPLES * sizeof(int32_t), &dummy_bytes, pdMS_TO_TICKS(100));

    static int32_t dc_offset = 0;
    size_t samples_captured = 0;

    /* 1. Așteptare Voice Trigger */
    bool sound_detected = false;
    while (!sound_detected) {
        size_t bytes_read = 0;
        esp_err_t ret = i2s_channel_read(rx_handle, raw_chunk, CHUNK_SAMPLES * sizeof(int32_t), &bytes_read, pdMS_TO_TICKS(1000));
        if (ret == ESP_OK && bytes_read > 0) {
            size_t read_samples = bytes_read / sizeof(int32_t);
            int64_t chunk_sum_abs = 0;

            for (size_t i = 0; i < read_samples; i++) {
                int16_t val_raw = (int16_t)(raw_chunk[i] >> 16);
                dc_offset = (dc_offset * 31 + val_raw) / 32;
                int16_t val = val_raw - (int16_t)dc_offset;

                int32_t val_amp = (int32_t)val * AUDIO_GAIN_FACTOR;
                if (val_amp > 32767) val_amp = 32767;
                else if (val_amp < -32768) val_amp = -32768;

                g_audio_psram_buf[i] = (int16_t)val_amp;
                chunk_sum_abs += (val_amp < 0) ? -val_amp : val_amp;
            }

            int chunk_avg_amp = (int)(chunk_sum_abs / read_samples);
            if (chunk_avg_amp >= VAD_SPEECH_THRESHOLD) {
                sound_detected = true;
                samples_captured = read_samples;
                ESP_LOGI(TAG, "Sunet detectat (Avg: %d >= %d)! Înregistrare în curs...",
                         chunk_avg_amp, VAD_SPEECH_THRESHOLD);
                break;
            }
        }
        if (gpio_get_level(GPIO_NUM_0) == 0) {
            ESP_LOGI(TAG, "Buton BOOT apăsat!");
            break;
        }
        esp_task_wdt_reset();
    }

    if (!sound_detected) {
        free(raw_chunk);
        esp_task_wdt_delete(NULL);
        return false;
    }

    /* 2. Înregistrare 100% în PSRAM */
    int silence_chunk_counter = 0;
    bool recording = true;

    while (recording && samples_captured < TOTAL_SAMPLES) {
        size_t samples_to_read = CHUNK_SAMPLES;
        if (samples_captured + samples_to_read > TOTAL_SAMPLES) {
            samples_to_read = TOTAL_SAMPLES - samples_captured;
        }

        size_t bytes_to_read = samples_to_read * sizeof(int32_t);
        size_t bytes_read = 0;

        esp_err_t ret = i2s_channel_read(rx_handle, raw_chunk, bytes_to_read, &bytes_read, pdMS_TO_TICKS(1000));
        if (ret == ESP_OK && bytes_read > 0) {
            size_t read_samples = bytes_read / sizeof(int32_t);
            int64_t chunk_sum_abs = 0;

            for (size_t i = 0; i < read_samples; i++) {
                int16_t val_raw = (int16_t)(raw_chunk[i] >> 16);
                dc_offset = (dc_offset * 31 + val_raw) / 32;
                int16_t val = val_raw - (int16_t)dc_offset;

                int32_t val_amp = (int32_t)val * AUDIO_GAIN_FACTOR;
                if (val_amp > 32767) val_amp = 32767;
                else if (val_amp < -32768) val_amp = -32768;

                g_audio_psram_buf[samples_captured++] = (int16_t)val_amp;
                chunk_sum_abs += (val_amp < 0) ? -val_amp : val_amp;
            }

            int chunk_avg_amp = (int)(chunk_sum_abs / read_samples);

            if (gpio_get_level(GPIO_NUM_0) == 0) {
                ESP_LOGI(TAG, "Oprire manuală prin buton BOOT.");
                break;
            }

            if (chunk_avg_amp >= VAD_SPEECH_THRESHOLD) {
                silence_chunk_counter = 0;
            } else {
                silence_chunk_counter++;
                /* 62 chunk-uri @ 512 samples = ~1.98s liniște */
                if (silence_chunk_counter >= 62) {
                    ESP_LOGI(TAG, "Liniște 2.0s detectată! Înregistrare gata (%zu samples).", samples_captured);
                    recording = false;
                    break;
                }
            }
        }
        esp_task_wdt_reset();
    }

    esp_task_wdt_delete(NULL);
    free(raw_chunk);

    /* 3. Actualizăm starea bufferului partajat fără să atingem flash-ul */
    xSemaphoreTake(g_audio_mutex, portMAX_DELAY);
    g_last_recorded_samples = samples_captured;
    xSemaphoreGive(g_audio_mutex);

    ESP_LOGI(TAG, "Audio pregătit instantaneu în RAM: %zu samples (%.2f secunde, %zu bytes PCM)",
             samples_captured, (double)samples_captured / SAMPLE_RATE, samples_captured * sizeof(int16_t));

    return (samples_captured > 0);
}

/* Transmisie directă din PSRAM către OpenAI Whisper prin HTTP POST */
static void send_audio_to_openai_whisper_ram(void)
{
    xSemaphoreTake(g_audio_mutex, portMAX_DELAY);
    size_t samples_count = g_last_recorded_samples;
    int16_t *audio_data = g_audio_psram_buf;
    xSemaphoreGive(g_audio_mutex);

    if (samples_count == 0 || !audio_data) {
        ESP_LOGE(TAG, "Nu există date audio în RAM de trimis către Whisper!");
        return;
    }

    ESP_LOGI(TAG, "=================================================");
    ESP_LOGI(TAG, " Trimitere directă din PSRAM către OpenAI Whisper (%zu samples)...", samples_count);
    ESP_LOGI(TAG, "=================================================");

    uint32_t pcm_bytes = samples_count * sizeof(int16_t);
    wav_header_t wav_hdr = create_wav_header(pcm_bytes, SAMPLE_RATE);
    uint32_t file_size = sizeof(wav_header_t) + pcm_bytes;

    char *response_buf = (char *)malloc(2048);
    if (!response_buf) {
        ESP_LOGE(TAG, "Alocare eșuată pentru bufferul de răspuns HTTP!");
        return;
    }

    const char *boundary = "ESP32Boundary7MA4YWxk";

    const char *model_header =
        "--ESP32Boundary7MA4YWxk\r\n"
        "Content-Disposition: form-data; name=\"model\"\r\n\r\n"
        "whisper-1\r\n";

    const char *language_header =
        "--ESP32Boundary7MA4YWxk\r\n"
        "Content-Disposition: form-data; name=\"language\"\r\n\r\n"
        "ro\r\n";

    const char *file_header =
        "--ESP32Boundary7MA4YWxk\r\n"
        "Content-Disposition: form-data; name=\"file\"; filename=\"speech_direct.wav\"\r\n"
        "Content-Type: audio/wav\r\n\r\n";

    const char *crlf = "\r\n";
    const char *footer = "--ESP32Boundary7MA4YWxk--\r\n";

    int total_len = strlen(model_header) + 
                    strlen(language_header) + 
                    strlen(file_header) + 
                    file_size + 
                    strlen(crlf) + 
                    strlen(footer);

    esp_http_client_config_t config = {};
    config.url = "https://api.openai.com/v1/audio/transcriptions";
    config.transport_type = HTTP_TRANSPORT_OVER_SSL;
    config.method = HTTP_METHOD_POST;
    config.crt_bundle_attach = esp_crt_bundle_attach;
    config.timeout_ms = 45000;
    config.buffer_size = 2048;
    config.buffer_size_tx = 2048;

    esp_http_client_handle_t client = esp_http_client_init(&config);
    if (!client) {
        ESP_LOGE(TAG, "Inițializare HTTP Client eșuată!");
        free(response_buf);
        return;
    }

    char auth_header[256];
    snprintf(auth_header, sizeof(auth_header), "Bearer %s", OPENAI_API_KEY);

    char content_type[128];
    snprintf(content_type, sizeof(content_type), "multipart/form-data; boundary=%s", boundary);

    esp_http_client_set_method(client, HTTP_METHOD_POST);
    esp_http_client_set_header(client, "User-Agent", "ESP32S3-Whisper/2.0");
    esp_http_client_set_header(client, "Authorization", auth_header);
    esp_http_client_set_header(client, "Content-Type", content_type);

    esp_err_t err = esp_http_client_open(client, total_len);
    if (err != ESP_OK) {
        ESP_LOGE(TAG, "Deschidere conexiune HTTPS eșuată: %s", esp_err_to_name(err));
        esp_http_client_cleanup(client);
        free(response_buf);
        return;
    }

    /* 1. Scriem câmpurile text */
    esp_http_client_write(client, model_header, strlen(model_header));
    esp_http_client_write(client, language_header, strlen(language_header));
    esp_http_client_write(client, file_header, strlen(file_header));

    /* 2. Scriem header-ul WAV generat în zbor */
    esp_http_client_write(client, (const char *)&wav_hdr, sizeof(wav_header_t));

    /* 3. Transmitem întregul buffer din PSRAM în bucăți de 4096 bytes */
    size_t bytes_sent = 0;
    const char *raw_ptr = (const char *)audio_data;

    while (bytes_sent < pcm_bytes) {
        size_t to_send = (pcm_bytes - bytes_sent > 4096) ? 4096 : (pcm_bytes - bytes_sent);
        int written = esp_http_client_write(client, raw_ptr + bytes_sent, to_send);
        if (written < 0) {
            ESP_LOGE(TAG, "Eroare la scrierea socket-ului SSL la offset %zu!", bytes_sent);
            break;
        }
        bytes_sent += written;
    }

    /* 4. Scriem terminatorul multipart */
    esp_http_client_write(client, crlf, strlen(crlf));
    esp_http_client_write(client, footer, strlen(footer));

    esp_http_client_fetch_headers(client);
    int status_code = esp_http_client_get_status_code(client);
    ESP_LOGI(TAG, "OpenAI HTTP Response Code: %d", status_code);

    int read_len = esp_http_client_read_response(client, response_buf, 2047);
    if (read_len >= 0) {
        response_buf[read_len] = '\0';
        ESP_LOGI(TAG, "====================================================================");
        ESP_LOGI(TAG, " OPENAI WHISPER RESULT: %s", response_buf);
        ESP_LOGI(TAG, "====================================================================");

        uart_write_bytes(UART_PORT_NUM, response_buf, read_len);
        uart_write_bytes(UART_PORT_NUM, "\n", 1);
    } else {
        ESP_LOGE(TAG, "Eroare la citirea răspunsului de la OpenAI!");
    }

    esp_http_client_cleanup(client);
    free(response_buf);
}

/* Handler Web: descarcă audio-ul direct din PSRAM generând headerul WAV */
static esp_err_t wav_download_handler(httpd_req_t *req)
{
    xSemaphoreTake(g_audio_mutex, portMAX_DELAY);
    size_t samples_count = g_last_recorded_samples;
    int16_t *audio_data = g_audio_psram_buf;

    if (samples_count == 0 || !audio_data) {
        xSemaphoreGive(g_audio_mutex);
        httpd_resp_send_err(req, HTTPD_404_NOT_FOUND, "Nu există nicio înregistrare disponibilă în RAM.");
        return ESP_FAIL;
    }

    uint32_t pcm_bytes = samples_count * sizeof(int16_t);
    wav_header_t wav_hdr = create_wav_header(pcm_bytes, SAMPLE_RATE);

    httpd_resp_set_type(req, "audio/wav");
    httpd_resp_set_hdr(req, "Content-Disposition", "attachment; filename=\"speech_verify.wav\"");

    /* Trimite mai întâi header-ul de 44 bytes */
    httpd_resp_send_chunk(req, (const char *)&wav_hdr, sizeof(wav_header_t));

    /* Trimite datele audio din PSRAM */
    const char *raw_ptr = (const char *)audio_data;
    size_t sent = 0;
    while (sent < pcm_bytes) {
        size_t chunk = (pcm_bytes - sent > 4096) ? 4096 : (pcm_bytes - sent);
        if (httpd_resp_send_chunk(req, raw_ptr + sent, chunk) != ESP_OK) {
            xSemaphoreGive(g_audio_mutex);
            httpd_resp_sendstr_chunk(req, NULL);
            return ESP_FAIL;
        }
        sent += chunk;
    }

    xSemaphoreGive(g_audio_mutex);
    httpd_resp_send_chunk(req, NULL, 0);
    ESP_LOGI(TAG, "Fișierul WAV a fost descărcat integral din PSRAM către browser!");
    return ESP_OK;
}

static const char html_page[] =
    "<!DOCTYPE html><html><head><meta name=\"viewport\" content=\"width=device-width, initial-scale=1\">"
    "<title>ESP32-S3 PSRAM Live Audio</title>"
    "<style>"
    "body{font-family:Arial,sans-serif;background:#0d1117;color:#c9d1d9;text-align:center;padding:40px 20px;margin:0;}"
    ".card{background:#161b22;border:1px solid #30363d;border-radius:12px;padding:30px;max-width:480px;margin:0 auto;box-shadow:0 8px 24px rgba(0,0,0,0.5);}"
    "h1{color:#58a6ff;font-size:22px;margin-bottom:8px;}"
    "audio{width:100%;margin:25px 0;outline:none;}"
    ".btn{display:inline-block;background:#238636;color:#ffffff;text-decoration:none;padding:12px 24px;border-radius:6px;font-weight:bold;font-size:15px;}"
    ".info{background:#0d1117;border:1px solid #30363d;border-radius:6px;padding:14px;margin-top:25px;font-size:13px;color:#8b949e;text-align:left;line-height:1.6;}"
    "</style></head><body><div class=\"card\">"
    "<h1>ESP32-S3 Live Voice Player</h1>"
    "<p>Stream direct din PSRAM (Zero Flash Delays)</p>"
    "<audio controls src=\"/download\"></audio>"
    "<div><a href=\"/download\" download=\"speech_verify.wav\" class=\"btn\">Download speech_verify.wav</a></div>"
    "<div class=\"info\">"
    "&bull; <b>Sursă:</b> PSRAM RAM Buffer<br>"
    "&bull; <b>Format:</b> 16,000 Hz, 16-bit Mono PCM<br>"
    "&bull; <b>Latență salvare disc:</b> 0 ms"
    "</div></div></body></html>";

static esp_err_t html_index_handler(httpd_req_t *req)
{
    httpd_resp_set_type(req, "text/html");
    httpd_resp_send(req, html_page, HTTPD_RESP_USE_STRLEN);
    return ESP_OK;
}

static httpd_handle_t start_webserver(void)
{
    httpd_handle_t server = NULL;
    httpd_config_t config = HTTPD_DEFAULT_CONFIG();
    config.lru_purge_enable = true;

    if (httpd_start(&server, &config) == ESP_OK) {
        httpd_uri_t root_uri = { .uri = "/", .method = HTTP_GET, .handler = html_index_handler, .user_ctx = NULL };
        httpd_register_uri_handler(server, &root_uri);

        httpd_uri_t download_uri = { .uri = "/download", .method = HTTP_GET, .handler = wav_download_handler, .user_ctx = NULL };
        httpd_register_uri_handler(server, &download_uri);

        return server;
    }
    return NULL;
}

static void wifi_event_handler(void* arg, esp_event_base_t event_base,
                               int32_t event_id, void* event_data)
{
    if (event_base == WIFI_EVENT && event_id == WIFI_EVENT_STA_START) {
        esp_wifi_connect();
    } else if (event_base == WIFI_EVENT && event_id == WIFI_EVENT_STA_DISCONNECTED) {
        ESP_LOGW(TAG, "Wi-Fi deconectat. Reconectare...");
        esp_wifi_connect();
    } else if (event_base == IP_EVENT && event_id == IP_EVENT_STA_GOT_IP) {
        ip_event_got_ip_t* event = (ip_event_got_ip_t*) event_data;
        ESP_LOGI(TAG, "====================================================================");
        ESP_LOGI(TAG, " WI-FI CONECTAT: " IPSTR, IP2STR(&event->ip_info.ip));
        ESP_LOGI(TAG, " PLAYER WEB     : http://" IPSTR "/", IP2STR(&event->ip_info.ip));
        ESP_LOGI(TAG, "====================================================================");
        xEventGroupSetBits(s_wifi_event_group, WIFI_CONNECTED_BIT);
    }
}
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
extern "C" void app_main(void)
{
    esp_log_level_set(TAG, ESP_LOG_INFO);

    g_audio_mutex = xSemaphoreCreateMutex();

    ESP_LOGI(TAG, "Memorie SPIRAM liberă: %d bytes (~%d MB)",
             heap_caps_get_free_size(MALLOC_CAP_SPIRAM),
             heap_caps_get_free_size(MALLOC_CAP_SPIRAM) / (1024 * 1024));

    /* Alocare permanentă buffer audio de 30 secunde în PSRAM (960 KB) */
    g_audio_psram_buf = (int16_t *)heap_caps_malloc(TOTAL_PCM_BYTES, MALLOC_CAP_SPIRAM);
    if (!g_audio_psram_buf) {
        ESP_LOGE(TAG, "CRITIC: Nu s-a putut aloca bufferul de 30s în PSRAM!");
        return;
    }

    esp_err_t ret = nvs_flash_init();
    if (ret == ESP_ERR_NVS_NO_FREE_PAGES || ret == ESP_ERR_NVS_NEW_VERSION_FOUND) {
        ESP_ERROR_CHECK(nvs_flash_erase());
        ret = nvs_flash_init();
    }
    ESP_ERROR_CHECK(ret);

    gpio_config_t io_conf = {
        .pin_bit_mask = (1ULL << GPIO_NUM_0),
        .mode = GPIO_MODE_INPUT,
        .pull_up_en = GPIO_PULLUP_ENABLE,
        .pull_down_en = GPIO_PULLDOWN_DISABLE,
        .intr_type = GPIO_INTR_DISABLE,
    };
    gpio_config(&io_conf);

    uart_config_t uart_config = {
        .baud_rate  = UART_BAUD_RATE,
        .data_bits  = UART_DATA_8_BITS,
        .parity     = UART_PARITY_DISABLE,
        .stop_bits  = UART_STOP_BITS_1,
        .flow_ctrl  = UART_HW_FLOWCTRL_DISABLE,
        .source_clk = UART_SCLK_DEFAULT,
    };
    ESP_ERROR_CHECK(uart_param_config(UART_PORT_NUM, &uart_config));
    ESP_ERROR_CHECK(uart_set_pin(UART_PORT_NUM, UART_TX_PIN, UART_RX_PIN, UART_PIN_NO_CHANGE, UART_PIN_NO_CHANGE));
    ESP_ERROR_CHECK(uart_driver_install(UART_PORT_NUM, BUF_SIZE * 2, 0, 0, NULL, 0));

    wifi_init_sta();
    sync_sntp_time();

    i2s_chan_handle_t rx_handle = init_inmp441_i2s();
    start_webserver();

    char tx_json[256];
    uint8_t rx_buf[BUF_SIZE];
    int seq_num = 1;

    while (1)
    {
        ESP_LOGI(TAG, "Ciclul #%d pregătit...", seq_num);

        bool has_speech = record_and_evaluate_speech(rx_handle);

        if (has_speech) {
            ESP_LOGI(TAG, "Vorbire detectată! Transmitere instantanee din PSRAM către Whisper...");
            send_audio_to_openai_whisper_ram();
        }

        snprintf(tx_json, sizeof(tx_json),
                 "{\"cmd\":\"motor_control\",\"left_speed\":100,\"right_speed\":100,\"servo_angle\":90,\"seq\":%d}\n",
                 seq_num);

        uart_flush_input(UART_PORT_NUM);
        uart_write_bytes(UART_PORT_NUM, tx_json, strlen(tx_json));

        int len = uart_read_bytes(UART_PORT_NUM, rx_buf, sizeof(rx_buf) - 1, pdMS_TO_TICKS(1000));
        if (len > 0) {
            rx_buf[len] = '\0';
        }

        seq_num++;
        vTaskDelay(pdMS_TO_TICKS(1000));
    }
}

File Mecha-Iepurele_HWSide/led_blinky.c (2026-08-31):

/*
 * Copyright 2019 NXP
 * All rights reserved.
 *
 * SPDX-License-Identifier: BSD-3-Clause
 */

#include "board.h"
#include "app.h"
#include "frdmmcxa153/board/pin_mux.h"
#include "frdmmcxa153/board/peripherals.h"
#include "fsl_gpio.h"
#include "fsl_port.h"
#include "fsl_clock.h"
#include "fsl_reset.h"
#include "fsl_pwm.h"
#include "fsl_debug_console.h"
#include <stdbool.h>

/*******************************************************************************
 * Definitions
 ******************************************************************************/
#define MOTOR_TEST_DUTY_CYCLE_PERCENT 35U
#define MOTOR_PWM_FREQ_HZ             10000U

/*******************************************************************************
 * Prototypes
 ******************************************************************************/
static void MotorDual_SetControlPwm(bool standby, uint8_t duty_a, uint8_t ain1, uint8_t ain2, uint8_t duty_b, uint8_t bin1, uint8_t bin2);
static void App_InitMotors(void);

/*******************************************************************************
 * Variables
 ******************************************************************************/
static volatile uint32_t g_seconds = 0U;
static volatile bool g_motorInitialized = false;

/*******************************************************************************
 * Code
 ******************************************************************************/
static void App_InitMotors(void)
{
    /* Enable peripheral clocks for GPIO, PORT, and FLEXPWM0 */
    CLOCK_EnableClock(kCLOCK_GatePORT2);
    CLOCK_EnableClock(kCLOCK_GatePORT3);
    CLOCK_EnableClock(kCLOCK_GateGPIO2);
    CLOCK_EnableClock(kCLOCK_GateGPIO3);
    CLOCK_EnableClock(kCLOCK_GateFLEXPWM0);

    /* Release peripheral resets */
    RESET_ReleasePeripheralReset(kGPIO2_RST_SHIFT_RSTn);
    RESET_ReleasePeripheralReset(kPORT2_RST_SHIFT_RSTn);
    RESET_ReleasePeripheralReset(kGPIO3_RST_SHIFT_RSTn);
    RESET_ReleasePeripheralReset(kPORT3_RST_SHIFT_RSTn);
    RESET_ReleasePeripheralReset(kFLEXPWM0_RST_SHIFT_RSTn);

    /* Enable PORT Input Buffer (IBE), High Drive Strength (DSE), and Pin Muxing for Motor Channel A pins */
    PORT2->PCR[5] = (PORT2->PCR[5] & ~(PORT_PCR_MUX_MASK | PORT_PCR_PE_MASK)) | PORT_PCR_MUX(kPORT_MuxAlt0) | PORT_PCR_IBE_MASK | PORT_PCR_DSE_MASK; /* AIN2 */
    PORT2->PCR[7] = (PORT2->PCR[7] & ~(PORT_PCR_MUX_MASK | PORT_PCR_PE_MASK)) | PORT_PCR_MUX(kPORT_MuxAlt0) | PORT_PCR_IBE_MASK | PORT_PCR_DSE_MASK; /* STBY_DRIVER */
    PORT3->PCR[0] = (PORT3->PCR[0] & ~(PORT_PCR_MUX_MASK | PORT_PCR_PE_MASK)) | PORT_PCR_MUX(kPORT_MuxAlt0) | PORT_PCR_IBE_MASK | PORT_PCR_DSE_MASK; /* AIN1 (High Drive for LED pin) */

    /* Configure PWMA pin on PORT3 with kPORT_MuxAlt5 (FlexPWMA0) and DSE/IBE enabled */
    PORT3->PCR[6] = (PORT3->PCR[6] & ~(PORT_PCR_MUX_MASK | PORT_PCR_PE_MASK)) | PORT_PCR_MUX(kPORT_MuxAlt5) | PORT_PCR_IBE_MASK | PORT_PCR_DSE_MASK; /* FlexPWMA0 (P3_6) */

    /* Enable PORT Input Buffer (IBE), High Drive Strength (DSE), and Pin Muxing for Motor Channel B pins */
    PORT3->PCR[12] = (PORT3->PCR[12] & ~(PORT_PCR_MUX_MASK | PORT_PCR_PE_MASK)) | PORT_PCR_MUX(kPORT_MuxAlt0) | PORT_PCR_IBE_MASK | PORT_PCR_DSE_MASK; /* BIN1 (High Drive for LED pin) */
    PORT3->PCR[13] = (PORT3->PCR[13] & ~(PORT_PCR_MUX_MASK | PORT_PCR_PE_MASK)) | PORT_PCR_MUX(kPORT_MuxAlt0) | PORT_PCR_IBE_MASK | PORT_PCR_DSE_MASK; /* BIN2 */

    /* Configure PWMB pin on PORT3 with kPORT_MuxAlt5 (FlexPWMA1) and DSE/IBE enabled */
    PORT3->PCR[8] = (PORT3->PCR[8] & ~(PORT_PCR_MUX_MASK | PORT_PCR_PE_MASK)) | PORT_PCR_MUX(kPORT_MuxAlt5) | PORT_PCR_IBE_MASK | PORT_PCR_DSE_MASK; /* FlexPWMA1 (P3_8) */

    /* Configure Motor direction and standby pins as digital GPIO outputs */
    gpio_pin_config_t out_config_low = {
        .pinDirection = kGPIO_DigitalOutput,
        .outputLogic = 0U
    };

    gpio_pin_config_t out_config_high = {
        .pinDirection = kGPIO_DigitalOutput,
        .outputLogic = 1U
    };

    GPIO_PinInit(BOARD_INITPINS_STBY_DRIVER_GPIO, BOARD_INITPINS_STBY_DRIVER_GPIO_PIN, &out_config_high);
    GPIO_PinInit(BOARD_INITPINS_AIN1_GPIO, BOARD_INITPINS_AIN1_GPIO_PIN, &out_config_high);
    GPIO_PinInit(BOARD_INITPINS_AIN2_GPIO, BOARD_INITPINS_AIN2_GPIO_PIN, &out_config_low);
    GPIO_PinInit(BOARD_INITPINS_BIN1_GPIO, BOARD_INITPINS_BIN1_GPIO_PIN, &out_config_high);
    GPIO_PinInit(BOARD_INITPINS_BIN2_GPIO, BOARD_INITPINS_BIN2_GPIO_PIN, &out_config_low);

    /* Local PWM configuration structure */
    pwm_config_t pwmConfig;
    PWM_GetDefaultConfig(&pwmConfig);
    pwmConfig.reloadLogic = kPWM_ReloadImmediate;
    pwmConfig.pairOperation = kPWM_Independent;

    /* Signal parameters with kPWM_LowTrue polarity to fix duty cycle inversion */
    pwm_signal_param_t pwmSignalSM0 = {
        .pwmChannel = kPWM_PwmA,
        .dutyCyclePercent = MOTOR_TEST_DUTY_CYCLE_PERCENT,
        .level = kPWM_LowTrue,
        .faultState = kPWM_PwmFaultState0,
        .pwmchannelenable = true,
        .deadtimeValue = 0U
    };

    pwm_signal_param_t pwmSignalSM1 = {
        .pwmChannel = kPWM_PwmA,
        .dutyCyclePercent = MOTOR_TEST_DUTY_CYCLE_PERCENT,
        .level = kPWM_LowTrue,
        .faultState = kPWM_PwmFaultState0,
        .pwmchannelenable = true,
        .deadtimeValue = 0U
    };

    /* Initialize PWM submodules SM0 (PWMA) and SM1 (PWMB) */
    PWM_Init(FLEXPWM0_PERIPHERAL, FLEXPWM0_SM0, &pwmConfig);
    PWM_Init(FLEXPWM0_PERIPHERAL, FLEXPWM0_SM1, &pwmConfig);

    /* Clear any latched fault flags in FLEXPWM0 hardware */
    FLEXPWM0_PERIPHERAL->FSTS = 0x000FU;

    /* Disable fault override logic on channel outputs */
    PWM_SetupFaultDisableMap(FLEXPWM0_PERIPHERAL, FLEXPWM0_SM0, FLEXPWM0_SM0_A, kPWM_faultchannel_0, 0U);
    PWM_SetupFaultDisableMap(FLEXPWM0_PERIPHERAL, FLEXPWM0_SM1, FLEXPWM0_SM1_A, kPWM_faultchannel_0, 0U);

    /* Setup PWM outputs for SM0 and SM1 at 10 kHz Edge-Aligned */
    PWM_SetupPwm(FLEXPWM0_PERIPHERAL, FLEXPWM0_SM0, &pwmSignalSM0, 1U, kPWM_EdgeAligned, MOTOR_PWM_FREQ_HZ, 12000000U);
    PWM_SetupPwm(FLEXPWM0_PERIPHERAL, FLEXPWM0_SM1, &pwmSignalSM1, 1U, kPWM_EdgeAligned, MOTOR_PWM_FREQ_HZ, 12000000U);

    /* Unmask output channels and route PWM generator signals to output pins */
    PWM_SetChannelOutput(FLEXPWM0_PERIPHERAL, FLEXPWM0_SM0, FLEXPWM0_SM0_A, kPWM_NormalState);
    PWM_SetChannelOutput(FLEXPWM0_PERIPHERAL, FLEXPWM0_SM1, FLEXPWM0_SM1_A, kPWM_NormalState);
    PWM_SetupForceSignal(FLEXPWM0_PERIPHERAL, FLEXPWM0_SM0, FLEXPWM0_SM0_A, kPWM_UsePwm);
    PWM_SetupForceSignal(FLEXPWM0_PERIPHERAL, FLEXPWM0_SM1, FLEXPWM0_SM1_A, kPWM_UsePwm);

    /* Update initial duty cycles */
    PWM_UpdatePwmDutycycle(FLEXPWM0_PERIPHERAL, FLEXPWM0_SM0, FLEXPWM0_SM0_A, kPWM_EdgeAligned, MOTOR_TEST_DUTY_CYCLE_PERCENT);
    PWM_UpdatePwmDutycycle(FLEXPWM0_PERIPHERAL, FLEXPWM0_SM1, FLEXPWM0_SM1_A, kPWM_EdgeAligned, MOTOR_TEST_DUTY_CYCLE_PERCENT);
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

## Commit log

2026-08-24 added project electrical scheme, and 3D models without the correct motor mount
    [4wd_arduino_buggy_motor_mount_v1.dxf, 4wd_smart_buggy_chassis_1piece.3mf, 4wd_smart_buggy_chassis_1piece.stl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]
2026-08-31 added test projects for HW and SW
    [partitions.csv]
